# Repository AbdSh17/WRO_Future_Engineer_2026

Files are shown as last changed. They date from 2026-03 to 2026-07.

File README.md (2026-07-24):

<p align="center">
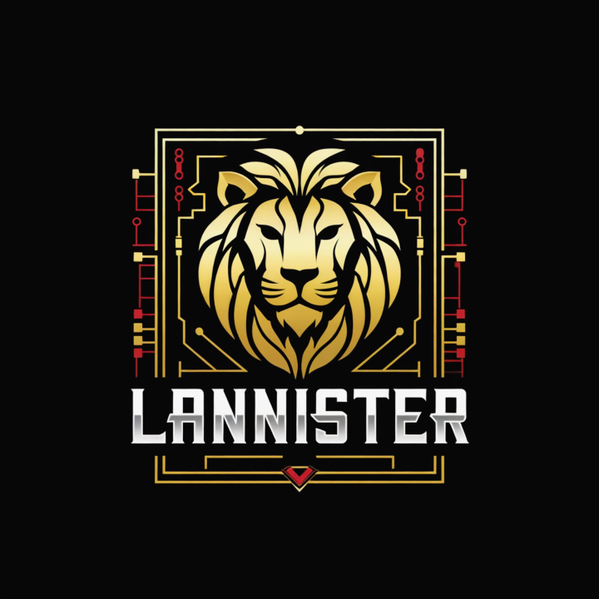
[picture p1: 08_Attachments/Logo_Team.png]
Team Lannister Logo
  
</p>

<h1 align="center">Team Lannister — WRO 2026 Future Engineers</h1>

<p align="center">
  <em>A self-driving car, built from scratch.</em>
</p>

<p align="center">
  <em>Hear me Roar.</em>
</p>

---

## Table of Contents

- [1. The Team](#1-the-team)
- [2. The Challenge](#2-the-challenge)
- [3. Mechanical Design](#3-mechanical-design)
  - [3.1 Chassis — Three Levels](#31-chassis--three-levels)
  - [3.2 Chassis & Deck Drawings](#32-chassis--deck-drawings)
  - [3.3 Steering — Ackermann Geometry](#33-steering--ackermann-geometry)
  - [3.4 Drivetrain](#34-drivetrain)
  - [3.5 Design Iterations](#35-design-iterations)
- [4. Hardware Overview](#4-hardware-overview)
  - [4.1 The Two Brains: ESP32 + Raspberry Pi 5](#41-the-two-brains-esp32--raspberry-pi-5)
  - [4.2 Vision: Raspberry Pi Camera Module 3](#42-vision-raspberry-pi-camera-module-3)
  - [4.3 Bill of Materials](#43-bill-of-materials)
  - [4.4 Power Architecture](#44-power-architecture)
  - [4.5 Wiring](#45-wiring)
- [5. Software](#5-software)
- [6. The Vehicle](#6-the-vehicle)
- [7. Videos](#7-videos)
- [8. Repository Map](#8-repository-map)
- [9. Build & Run](#9-build--run)
- [10. Behind the Build](#10-behind-the-build)

---

## 1. The Team

<table align="center">
<tr>
<td align="center" width="380">
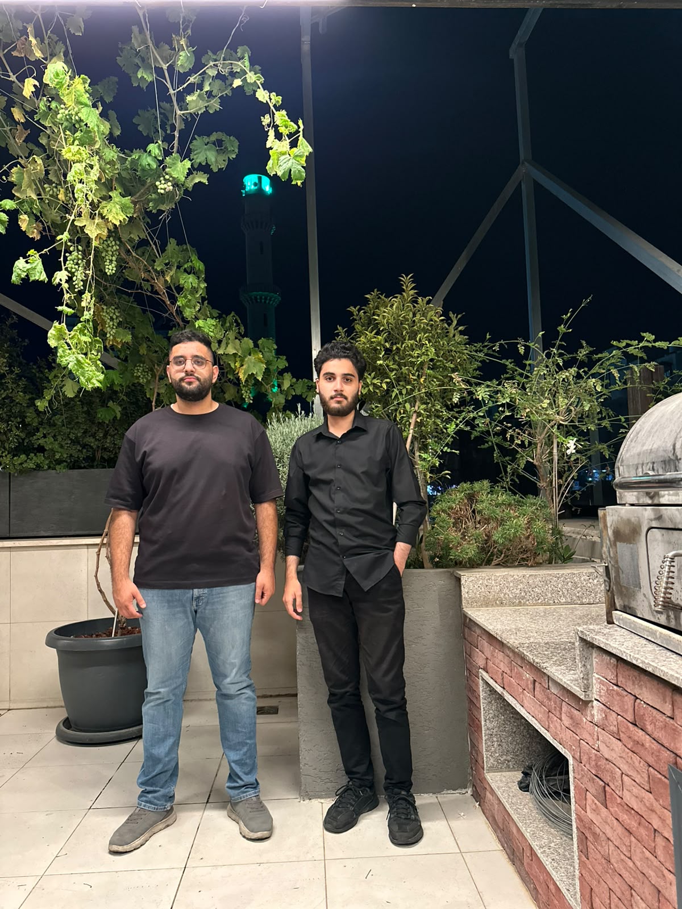
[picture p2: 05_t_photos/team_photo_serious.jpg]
<br/>
<sub><b>The official photo</b></sub>
</td>
<td align="center" width="380">
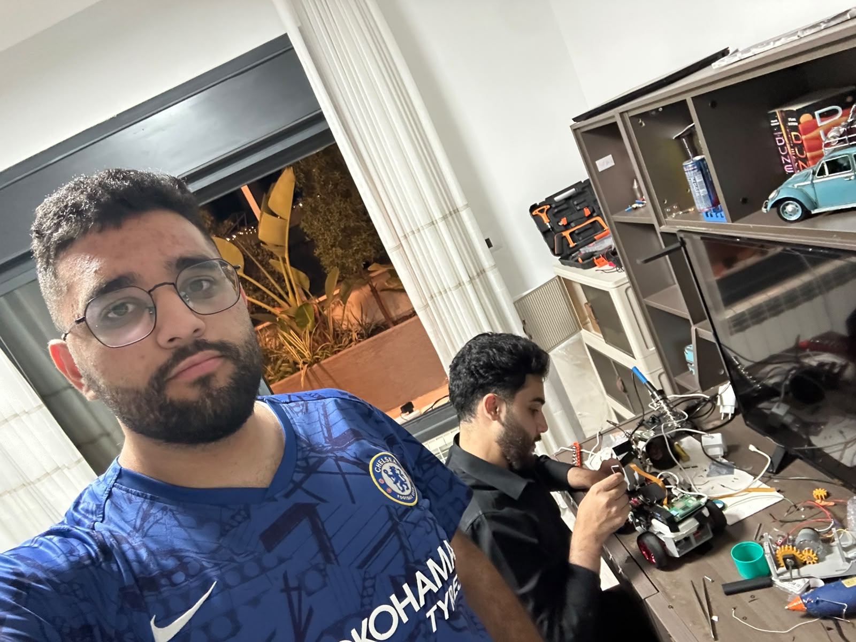
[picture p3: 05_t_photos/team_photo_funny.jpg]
<br/>
<sub><b>The one that actually looks like us</b></sub>
</td>
</tr>
</table>

---

<table align="center">
<tr>
<td align="center" width="300">
<br/>
<sub><b>Abdalraheem Shuaibi</b></sub><br/>
<sub>Hardware & PCB Design / Software</sub>
</td>
</tr>
</table>

I'm a 21-year-old Computer Engineering student at Birzeit University. I started learning embedded systems and firmware development about two years ago — largely self-taught, out of necessity. Structured resources for this kind of work are scarce where I'm from, so my path went from basic circuits and electronics theory all the way to PCB design, and from simple Arduino sketches to FreeRTOS and ESP-IDF, the same stack powering this robot.

Alongside this competition, I've been juggling a graduation project funded by the EU and the Palestinian Ministry of Health — a commitment that's demanded careful time management this season.

This isn't my first attempt at WRO Future Engineers. I competed alone in the 2025 season and things were going well, until a sensor burned out just before the local competition, ending that run early. That experience is a big part of why this repository exists in the form it does now — more testing, more documentation, fewer single points of failure.

---

<table align="center">
<tr>
<td align="center" width="300">
<br/>
<sub><b>Abdulrahman Sawalmeh</b></sub><br/>
<sub>Mechanical Design / Research / Hardware</sub>
</td>
</tr>
</table>

I'm a 21-year-old Computer Engineering student at Birzeit University. My main role on this team is the mechanical side — designing every printed part, building the physical robot, and making sure what looks right on screen actually works when it's sitting on a track. Along the way I also helped with component research, sourcing and buying parts, and sat in on algorithm discussions.

The 3D design side started about three months before this project, entirely self-taught. I picked up Fusion 360 out of curiosity — I thought it looked cool, kept going, and it turned into the thing I spent most of this competition doing. Three months in, a complete custom chassis with 16 printed parts and two rounds of mechanical iteration isn't where I expected to end up when I opened Fusion for the first time.

The hardest part wasn't any single part failing — it was the differential assembly. The obvious fixes for the axial play problem were both blocked by gear clearance on either side, and working around that constraint took longer than the original design. The retaining ring solution is simple in hindsight. It wasn't at the time.

This competition was the first time I built something that had to work in the real world, not just look right on screen. That gap between a model and a physical object that actually does its job — closing it is what made this season worth it.

---

## 2. The Challenge

<p align="center">
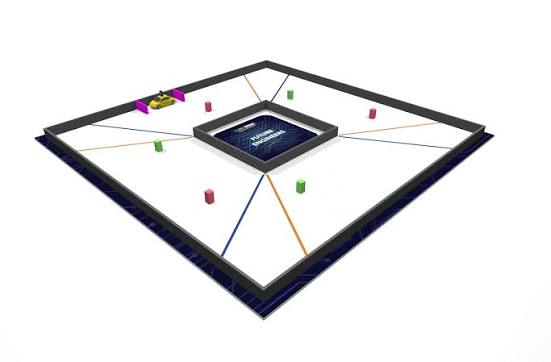
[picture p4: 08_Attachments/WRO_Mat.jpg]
WRO 2026 Future Engineers game field
  
</p>

WRO Future Engineers asks for a vehicle that can drive itself — no remote control, no shortcuts, just sensors, math, and code making decisions in real time. The car has to complete laps around a track that changes every round: walls move, corners narrow, and in the Obstacle Challenge, coloured pillars appear that the car has to read and respond to correctly. Get it wrong, and the round ends early.

It's a small, contained problem on paper. In practice, it touches almost every corner of engineering: mechanical design, power distribution, real-time firmware, computer vision, and the occasional very frustrating GPIO conflict at 2 AM.

---

## 3. Mechanical Design

Every structural part of this vehicle is custom-designed and 3D-printed. Nothing here is off the shelf except the WLTOYS 144001 differential and the wheels — everything else, from the chassis plate to the servo arm, was modelled in Fusion 360 and iterated through at least one physical revision. Full technical documentation, iteration stories, and manufacturing notes live in [`03_Models/00_models.md`](03_Models/00_models.md).

---

### 3.1 Chassis — Three Levels

The 300 × 200 mm footprint limit means the layout grows upward, not outward. One plate — `main_base` (254 × 100 mm) — carries everything, with standoff columns supporting two raised decks above it.

<table align="center">
<tr>
<td align="center" width="500">
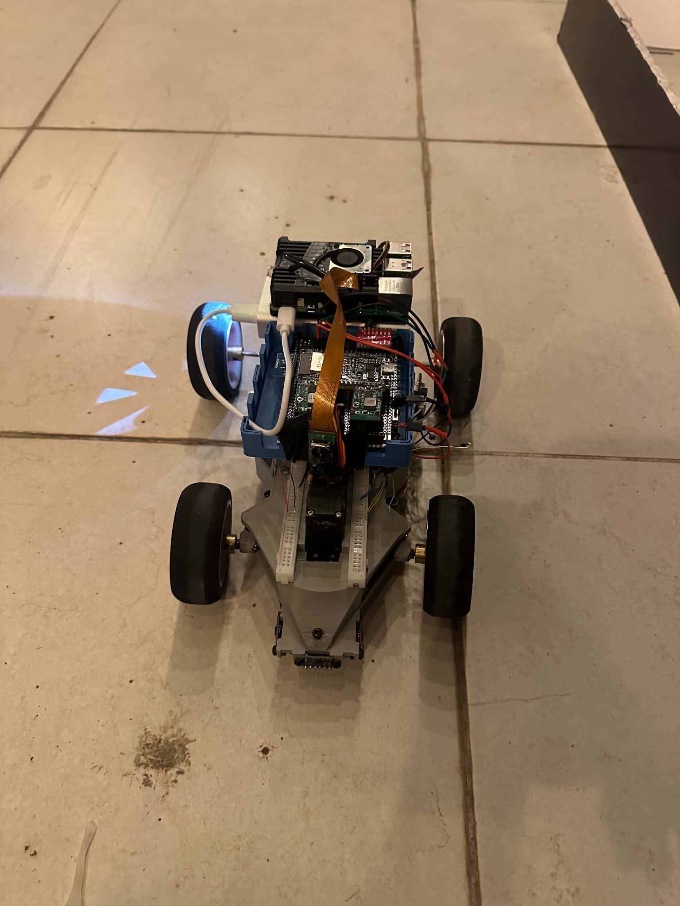
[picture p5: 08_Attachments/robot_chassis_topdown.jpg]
<br/>
<sub><b>Pi 5 and ESP32 stacked on the upper decks, fully wired</b></sub>
</td>
</tr>
</table>

| Level | Part | What lives there |
|---|---|---|
| Ground plate | `main_base` | Motor (mount built into the plate), differential assembly, steering knuckles, column standoffs |
| Front deck | `front_top` | MG996R steering servo, camera mast |
| Middle deck | `middle_top` | Main soldered PCB — see [`04_PCB`](04_PCB/00_PCB.md) |
| Rear deck | `back_top` | Raspberry Pi 5 + power bank |
| Mast | `camera_holder` | Camera Module 3, raised 154.7 mm above the chassis and angled at the track |

Two decisions behind this layout that are worth naming:

**The motor mount is part of the chassis plate, not a bracket.** The JGB37-520 sits in a pocket extruded directly into `main_base`. One fewer part to print, no joint to come loose from vibration, and the motor-to-differential alignment is determined by the geometry of a single piece rather than assembly accuracy.

**Electronics decks are removable.** Each deck comes off with a few screws, so electrical work never requires touching the drivetrain and mechanical work never requires unscrewing electronics. During a competition day, that separation is the difference between a five-minute fix and a full teardown.

---

### 3.2 Chassis & Deck Drawings

Click any drawing to open the full dimensioned PDF.

**Chassis, Decks & Camera**

<table align="center">
<tr>
<td align="center" width="370">
<a href="03_Models/drawings/main_base.pdf">
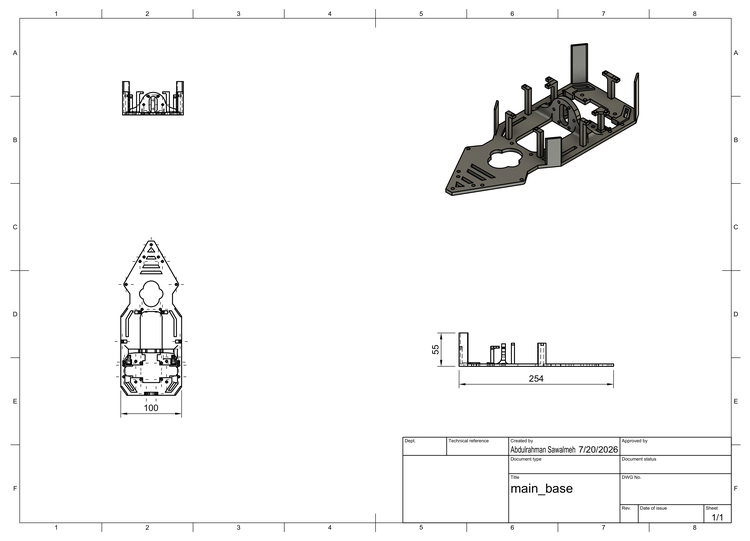
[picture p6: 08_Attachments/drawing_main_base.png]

</a><br/>
<sub><b><a href="03_Models/drawings/main_base.pdf">main_base.pdf</a> — Chassis plate (254 × 100 × 55 mm)</b></sub>
</td>
<td align="center" width="370">
<a href="03_Models/drawings/front_top.pdf">
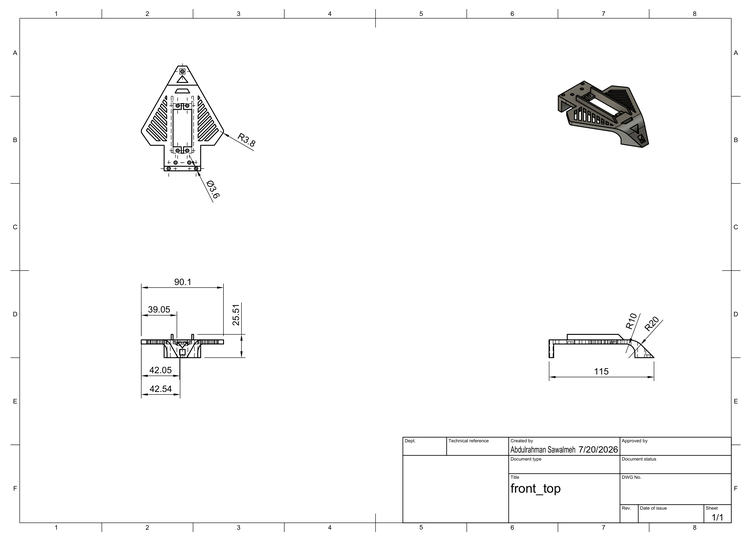
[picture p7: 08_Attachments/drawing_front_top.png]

</a><br/>
<sub><b><a href="03_Models/drawings/front_top.pdf">front_top.pdf</a> — Servo & camera deck (90 × 115 × 25 mm)</b></sub>
</td>
</tr>
<tr>
<td align="center" width="370">
<a href="03_Models/drawings/mid_top.pdf">
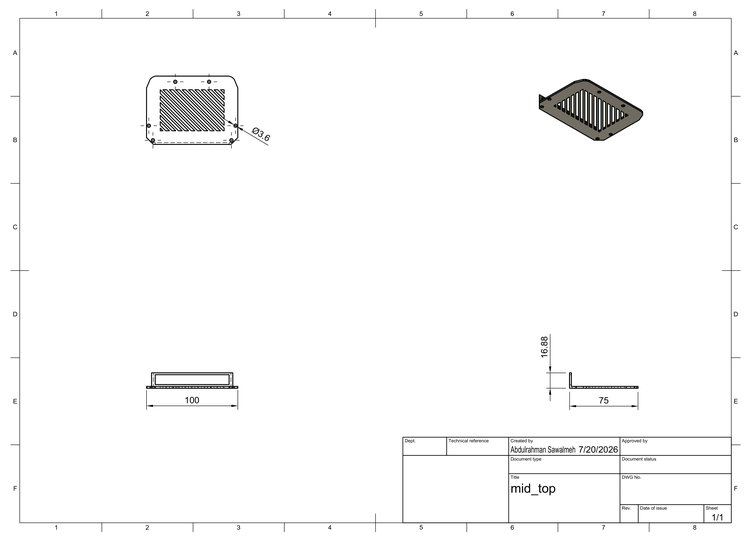
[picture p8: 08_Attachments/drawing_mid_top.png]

</a><br/>
<sub><b><a href="03_Models/drawings/mid_top.pdf">mid_top.pdf</a> — PCB platform (100 × 75 × 17 mm)</b></sub>
</td>
<td align="center" width="370">
<a href="03_Models/drawings/back_top.pdf">
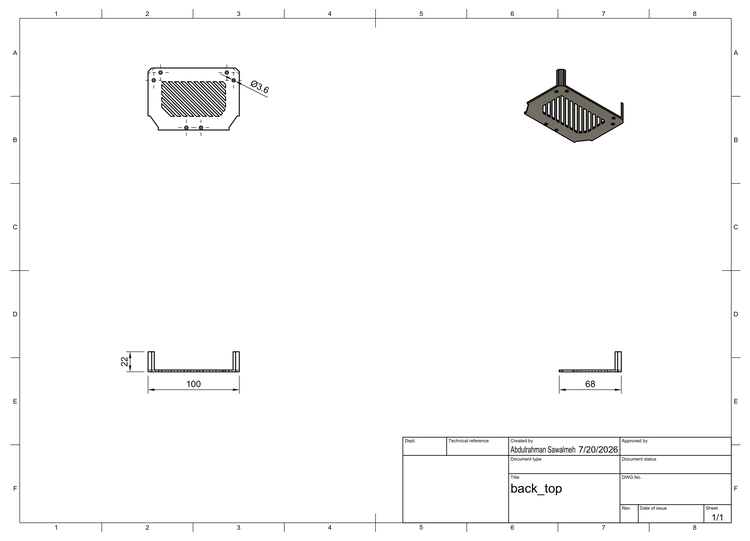
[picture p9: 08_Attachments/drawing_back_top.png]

</a><br/>
<sub><b><a href="03_Models/drawings/back_top.pdf">back_top.pdf</a> — Pi & power bank deck (100 × 68 × 22 mm)</b></sub>
</td>
</tr>
</table>

<table align="center">
<tr>
<td align="center" width="500">
<a href="03_Models/drawings/camera_holder.pdf">
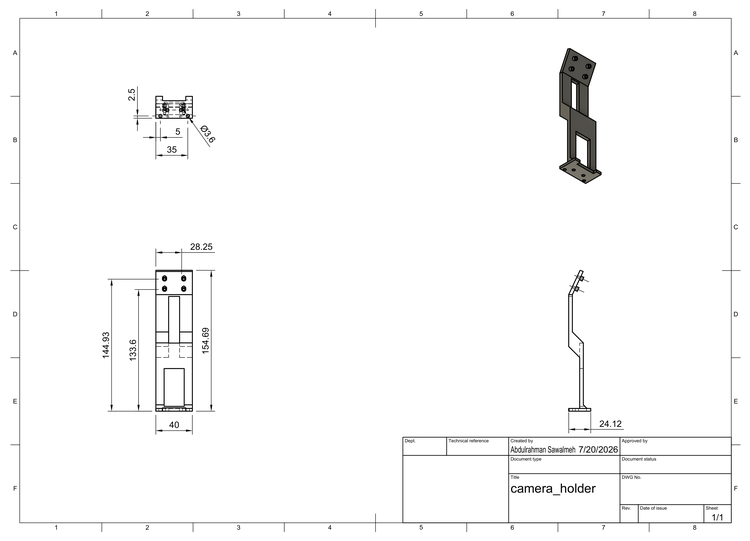
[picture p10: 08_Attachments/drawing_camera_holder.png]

</a><br/>
<sub><b><a href="03_Models/drawings/camera_holder.pdf">camera_holder.pdf</a> — Camera mast (40 × 24 × 154.7 mm) — the tallest printed part, raising the lens above the vehicle body</b></sub>
</td>
</tr>
</table>

---

### 3.3 Steering — Ackermann Geometry

The front wheels don't turn at the same angle — they can't. In any turn, the inner wheel follows a tighter arc than the outer one, so turning both wheels by the same amount always forces one of them to scrub sideways. Ackermann geometry fixes this by angling the steering linkage so the inner wheel always steers sharper than the outer one, pointing every wheel at a common turn center.

<table align="center">
<tr>
<td align="center" width="400">
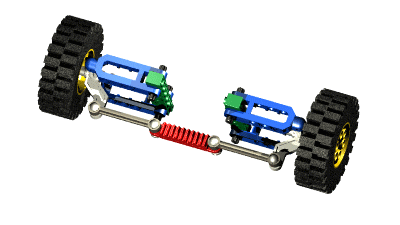
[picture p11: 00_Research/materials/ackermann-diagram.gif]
<br/>
<sub><b>Ackermann geometry in action</b></sub>
</td>
<td align="center" width="400">
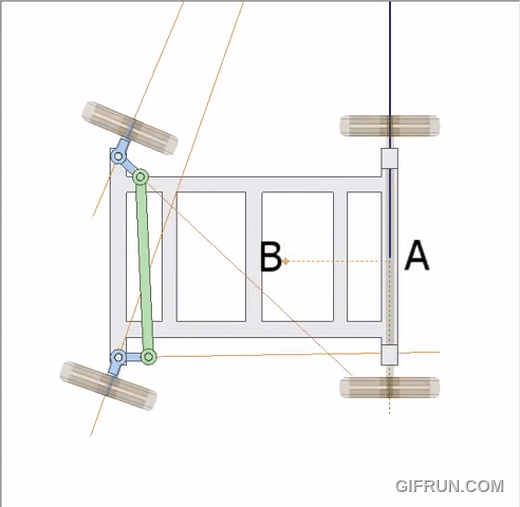
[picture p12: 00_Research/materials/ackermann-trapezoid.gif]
<br/>
<sub><b>The trapezoid linkage</b></sub>
</td>
</tr>
</table>

The geometry is implemented in three printed parts: the `left_knuckle` and `right_knuckle` pivot on kingpins at the chassis, and the `ackerman_rod` connects both knuckle eyes with a servo arm driving its center. The tie-rod eyes are angled inward so the line through each kingpin and its eye converges at the rear axle — the Ackermann condition. Verified directly in CAD:

<table align="center">
<tr>
<td align="center" width="350">
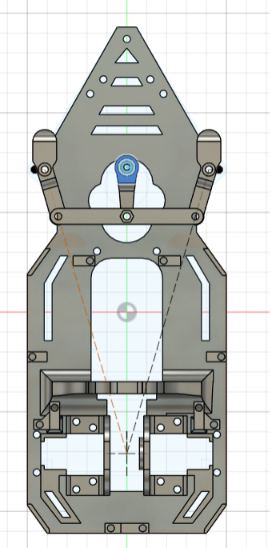
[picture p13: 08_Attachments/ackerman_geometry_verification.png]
<br/>
<sub><b>Top view in Fusion 360 — construction lines from the steering pivots converge at the rear axle centerline</b></sub>
</td>
</tr>
</table>

Full geometry, math, and the comparison against parallel steering is in [`00_Research/04_mechanical/02_ackermann-steering.md`](00_Research/04_mechanical/02_ackermann-steering.md). The torque requirement that selected the MG996R servo is in [`00_Research/03_components_selection/02_servo-torque-requirement.md`](00_Research/03_components_selection/02_servo-torque-requirement.md).

**Steering parts drawings**

<table align="center">
<tr>
<td align="center" width="250">
<a href="03_Models/drawings/ackerman_rod.pdf">
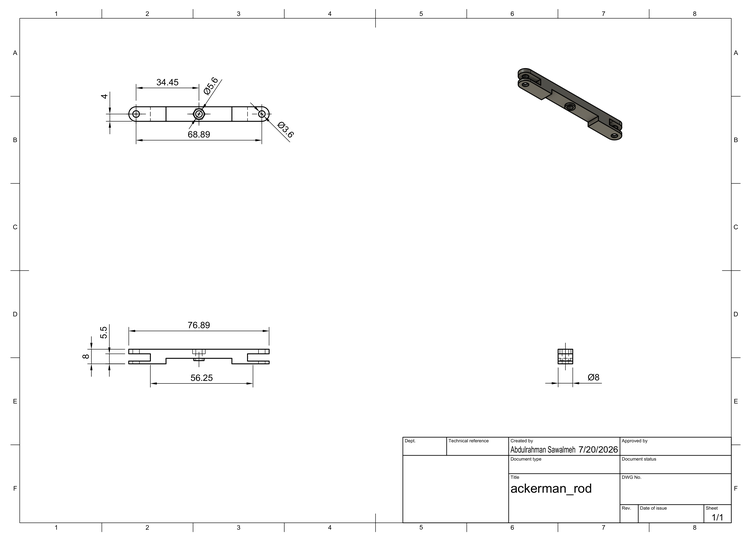
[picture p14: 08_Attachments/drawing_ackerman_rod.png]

</a><br/>
<sub><b><a href="03_Models/drawings/ackerman_rod.pdf">ackerman_rod.pdf</a><br/>Tie rod (76.9 × 8 × 8 mm)</b></sub>
</td>
<td align="center" width="250">
<a href="03_Models/drawings/knuckles.pdf">
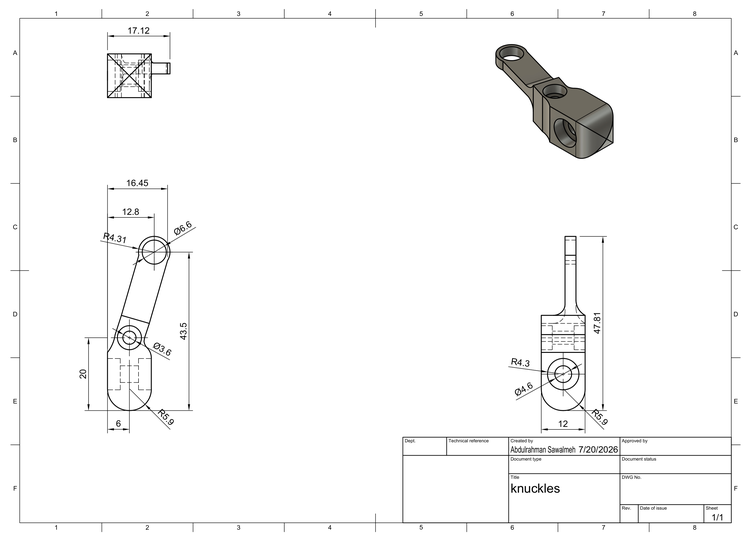
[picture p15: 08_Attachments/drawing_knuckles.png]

</a><br/>
<sub><b><a href="03_Models/drawings/knuckles.pdf">knuckles.pdf</a><br/>L/R knuckles (17 × 47.8 × 12 mm)</b></sub>
</td>
<td align="center" width="250">
<a href="03_Models/drawings/servo_arm.pdf">
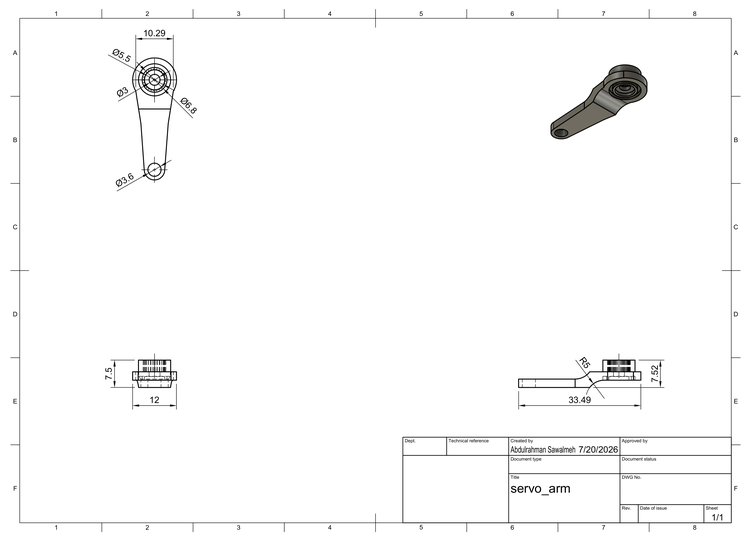
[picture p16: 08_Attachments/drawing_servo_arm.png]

</a><br/>
<sub><b><a href="03_Models/drawings/servo_arm.pdf">servo_arm.pdf</a><br/>Servo arm (33.5 × 12 × 7.5 mm)</b></sub>
</td>
</tr>
</table>

---

### 3.4 Drivetrain

A single JGB37-520 motor drives both rear wheels through a WLTOYS 144001 open differential — an off-the-shelf RC part that needed a fully custom mounting system because it was never designed for this chassis. The mounting system is five printed parts around a single off-the-shelf differential.

<table align="center">
<tr>
<td align="center" width="400">
<br/>
<sub><b>The differential in motion</b></sub>
</td>
<td align="center" width="400">
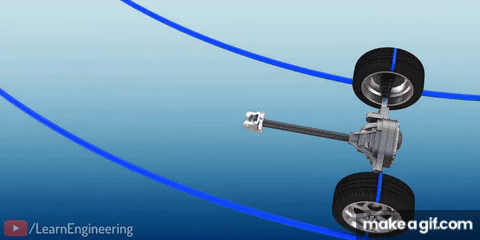
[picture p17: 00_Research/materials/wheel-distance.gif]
<br/>
<sub><b>Inner vs. outer wheel arc — why it matters</b></sub>
</td>
</tr>
</table>

Torque path: motor → bevel pinion (`motor_gear`) → differential crown → drive cups (`differantial_cup`) → 4 mm shafts → rear wheels. The differential splits torque purely mechanically — one motor, gears doing the work — which keeps us compliant with rule 11.5 (electronic differentials, one motor per side, are banned) while still letting the two rear wheels rotate at different speeds in corners.

Full drivetrain reasoning is in [`00_Research/04_mechanical/01_Differential.md`](00_Research/04_mechanical/01_Differential.md).

**Drivetrain parts drawings**

<table align="center">
<tr>
<td align="center" width="370">
<a href="03_Models/drawings/motor_gear.pdf">
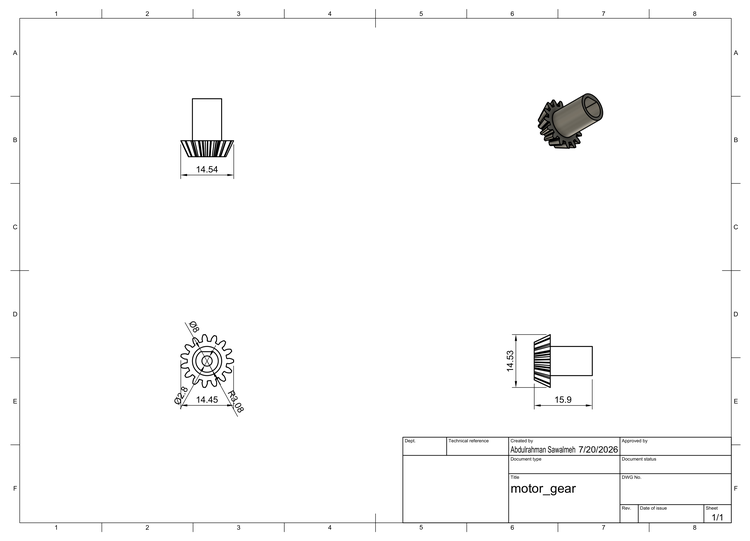
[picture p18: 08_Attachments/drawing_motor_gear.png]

</a><br/>
<sub><b><a href="03_Models/drawings/motor_gear.pdf">motor_gear.pdf</a> — Bevel pinion (14.5 × 15.9 × 14.5 mm)</b></sub>
</td>
<td align="center" width="370">
<a href="03_Models/drawings/differantial_rings_holder.pdf">
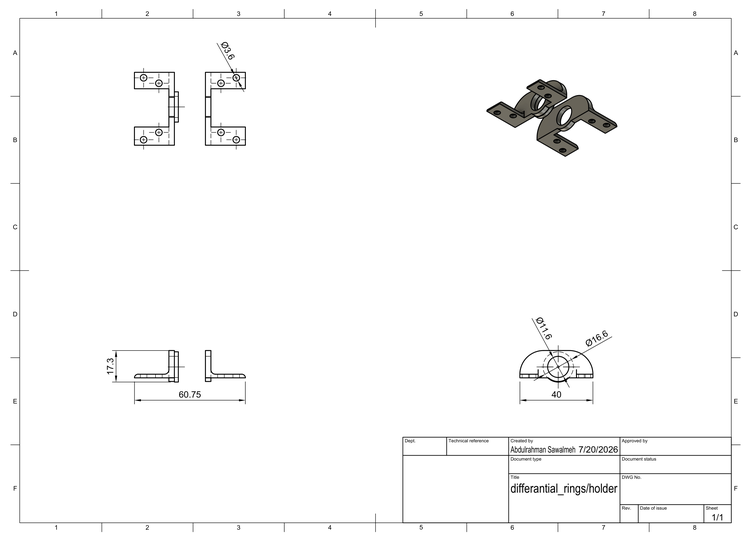
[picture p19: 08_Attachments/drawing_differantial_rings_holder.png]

</a><br/>
<sub><b><a href="03_Models/drawings/differantial_rings&holder.pdf">differantial_rings&holder.pdf</a> — Carrier rings + retaining ring</b></sub>
</td>
</tr>
<tr>
<td align="center" width="370">
<a href="03_Models/drawings/differantial_cup.pdf">
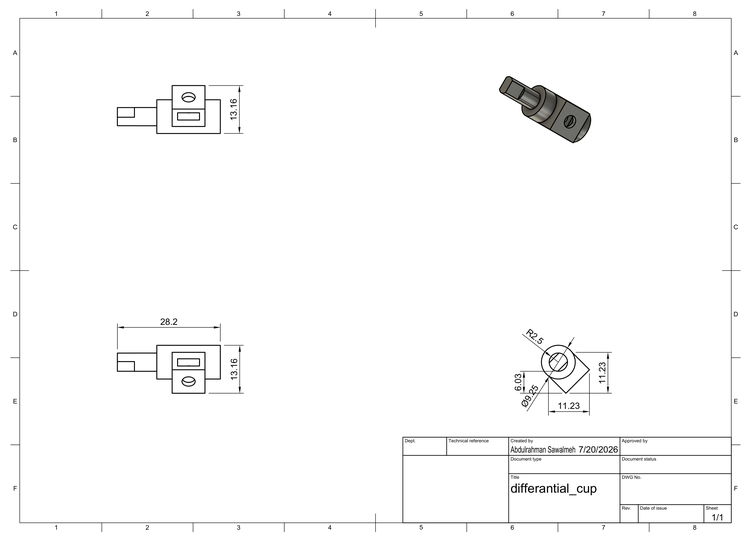
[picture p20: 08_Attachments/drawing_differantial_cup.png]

</a><br/>
<sub><b><a href="03_Models/drawings/differantial_cup.pdf">differantial_cup.pdf</a> — Drive coupling cup (28.2 × 13.2 × 13.2 mm)</b></sub>
</td>
<td align="center" width="370">
<a href="03_Models/drawings/shaft_holder.pdf">
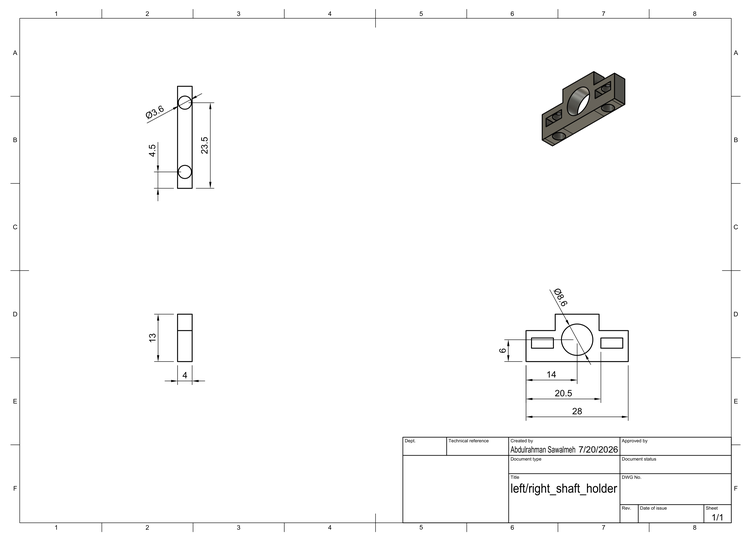
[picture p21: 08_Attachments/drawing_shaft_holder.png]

</a><br/>
<sub><b><a href="03_Models/drawings/shaft_holder.pdf">shaft_holder.pdf</a> — Outboard bearing block (28 × 13 mm, 4 mm shaft)</b></sub>
</td>
</tr>
</table>

---

### 3.5 Design Iterations

The drivetrain didn't work on the first try. Two physical problems had to be solved before the car drove properly — both visible in the current set of parts.

**Iteration 1 — Differential axial play.** The differential could slide sideways between its two carrier rings, shifting the bevel gear mesh and causing skips under load. The obvious fixes — thicken one carrier ring inward — were blocked by the motor's pinion on one side and a gear on the other. The solution was a separate 2.25 mm retaining ring (`differantial_holder`) glued to the right carrier, surrounding the differential bearing and closing the gap without entering either gear's space. A packaging constraint blocking both obvious solutions, forcing a third one.

**Iteration 2 — Rear wheel tilt.** Each drive shaft was originally supported only at its inboard end, at the differential carrier ring. The wheel hung on the free end of a cantilever and visibly tilted. Adding outboard bearing blocks (`left_shaft_holder`, `right_shaft_holder`) converted every shaft from a cantilevered load to a two-point supported one. The tilt disappeared.

Full iteration writeup with technical detail: [`03_Models/00_models.md#design-iterations`](03_Models/00_models.md#5-design-iterations)

---

## 4. Hardware Overview

### 4.1 The Two Brains: ESP32 + Raspberry Pi 5

The robot runs on two separate computers, each doing a different job.

<table align="center">
<tr>
<td align="center" width="260">
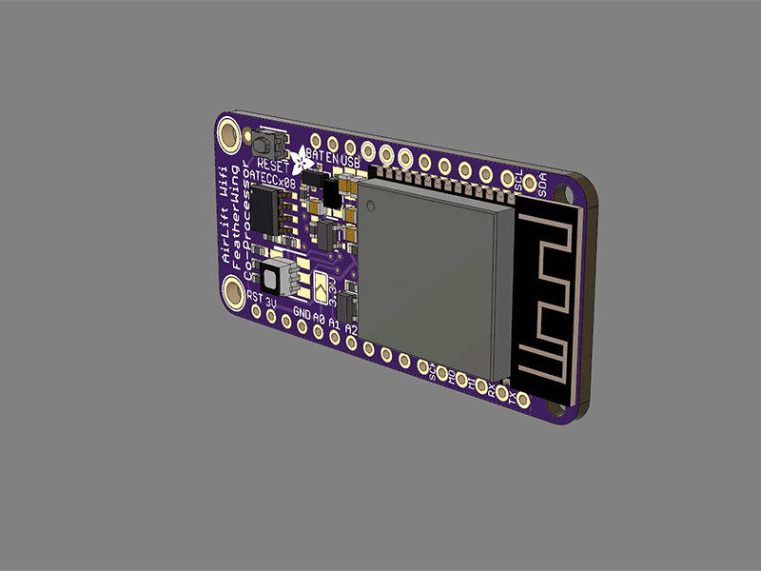
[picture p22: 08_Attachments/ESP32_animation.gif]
<br/>
<sub><b>ESP32 — real-time control</b></sub>
</td>
<td align="center" width="260">
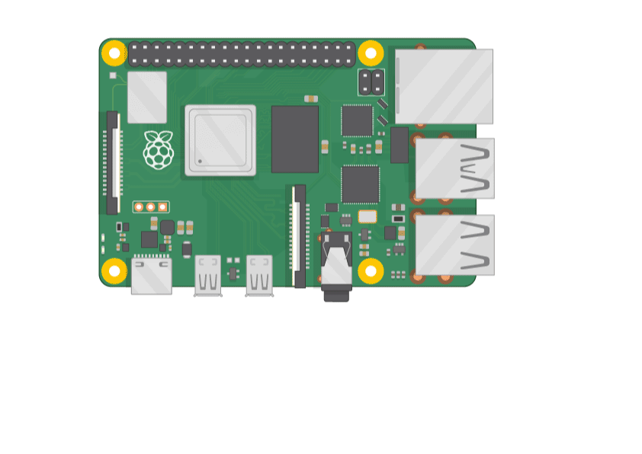
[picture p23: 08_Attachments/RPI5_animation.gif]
<br/>
<sub><b>Raspberry Pi 5 — vision</b></sub>
</td>
</tr>
</table>

The **ESP32** handles everything that has to happen in real time and can't afford to be late: reading the ToF sensors, reading the IMU, driving the motor, driving the steering servo, and running the state machine that decides what the car does next. It runs FreeRTOS, with each task — sensing, control, algorithm — kept strictly separated so a slow camera frame on the other board can never introduce jitter into a steering correction.

The **Raspberry Pi 5** is reserved for vision. Camera processing is comparatively heavy and doesn't need to run at the same tight, predictable cadence as motor control — so it lives on its own board entirely, talking to the ESP32 over UART.

<p align="center">
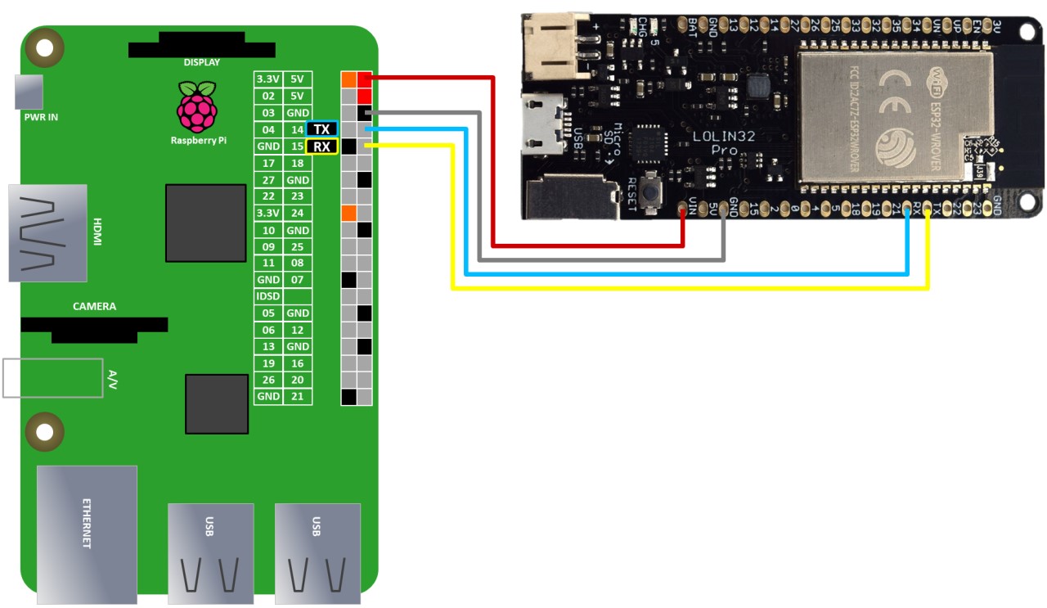
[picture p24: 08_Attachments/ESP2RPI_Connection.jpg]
ESP32 to Raspberry Pi connection
  
</p>
<p align="center"><sub><b>How the two boards talk to each other</b></sub></p>

Splitting the compute this way means a heavy vision frame never stalls a steering correction, and a firmware crash on the ESP32 doesn't take the camera pipeline down with it.

---

### 4.2 Vision: Raspberry Pi Camera Module 3

<table align="center">
<tr>
<td align="center" width="220">
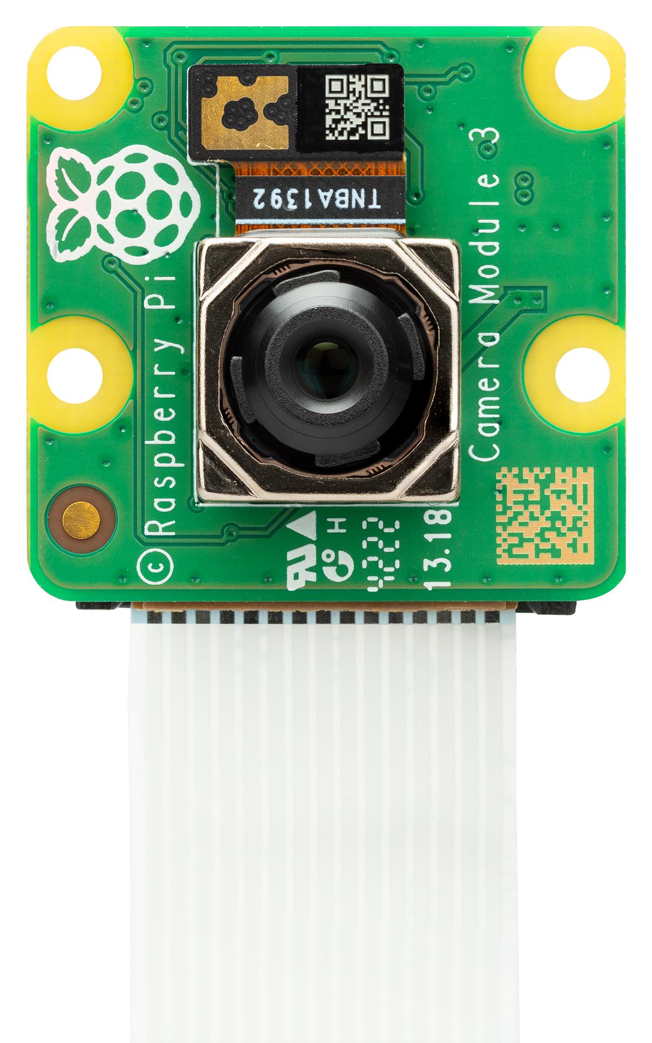
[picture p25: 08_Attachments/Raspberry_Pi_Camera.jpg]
<br/>
<sub><b>Camera Module 3, wide-angle</b></sub>
</td>
</tr>
</table>

We're using the **Raspberry Pi Camera Module 3**, wide-angle variant (~120° diagonal FoV), connected over the Pi 5's CSI port. The wide field of view matters here — the car needs to see pillars and track edges well before it's close enough for a narrow lens to catch them, giving the vision pipeline more time to make a decision.

<table align="center">
<tr>
<td align="center" width="400">
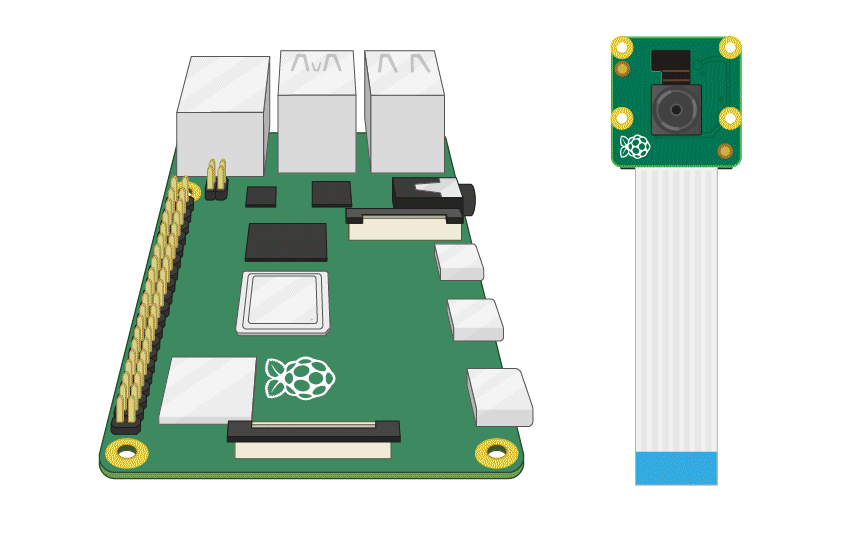
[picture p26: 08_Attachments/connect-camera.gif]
<br/>
<sub><b>Connecting the camera</b></sub>
</td>
</tr>
</table>

---

### 4.3 Bill of Materials

Every component on this robot was chosen against a calculated requirement first, not picked off a shelf. The motor's stall torque, the servo's stall torque, even the capacitor and resistor values, all trace back to a number derived in [`00_Research`](00_Research) before a single part was ordered.

---

**Compute — the two things that think**

<table align="center">
<tr>
<td align="center" width="240">
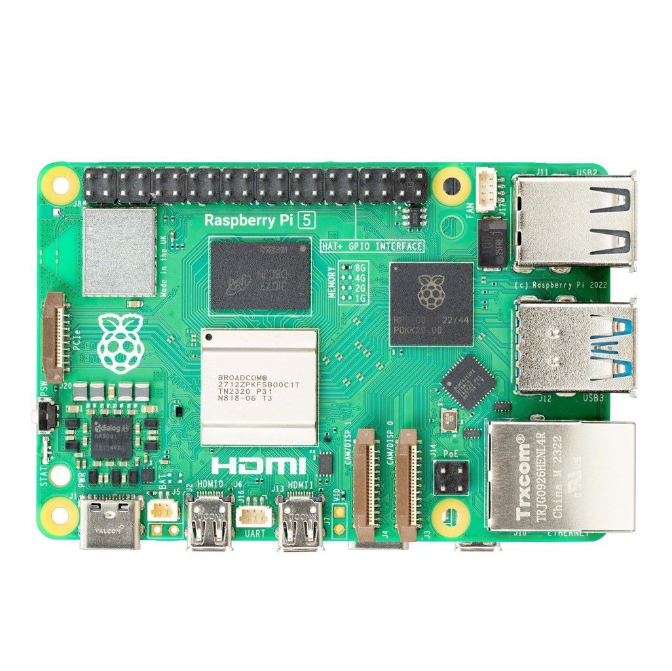
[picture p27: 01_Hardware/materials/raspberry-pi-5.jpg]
<br/>
<sub><b>Raspberry Pi 5</b></sub>
</td>
<td align="center" width="240">
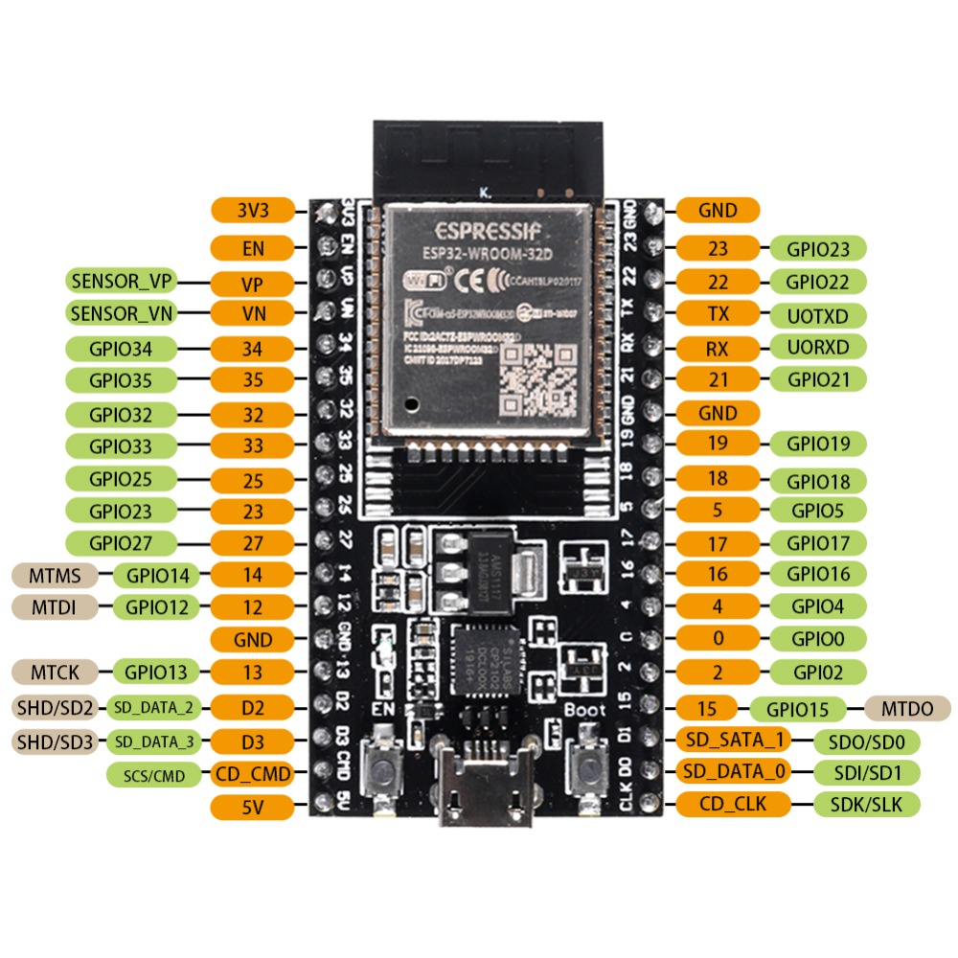
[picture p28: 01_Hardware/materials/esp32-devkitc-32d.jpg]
<br/>
<sub><b>ESP32-DEVKITC-32D</b></sub>
</td>
</tr>
</table>

The **Raspberry Pi 5** handles vision — capturing and processing camera frames, deciding where pillars are. The **ESP32-DEVKITC-32D** handles everything that needs to happen on a strict, predictable schedule: reading sensors, driving the motor, driving the servo, and running the state machine.

---

**Sensors — the three things that feel the track**

<table align="center">
<tr>
<td align="center" width="240">
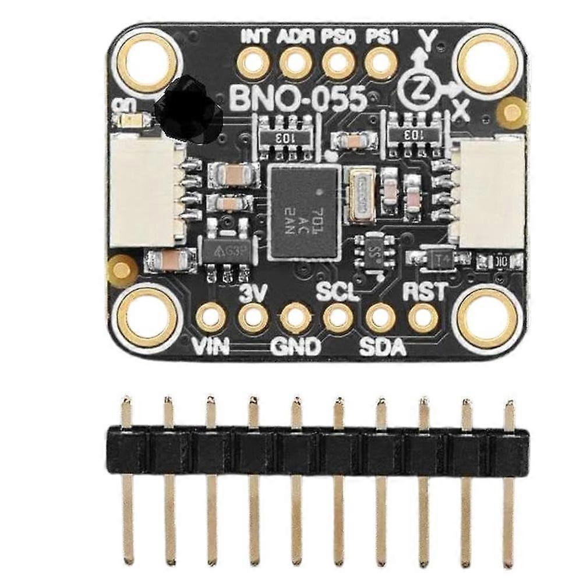
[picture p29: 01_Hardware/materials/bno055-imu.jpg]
<br/>
<sub><b>BNO055 IMU</b></sub>
</td>
<td align="center" width="240">
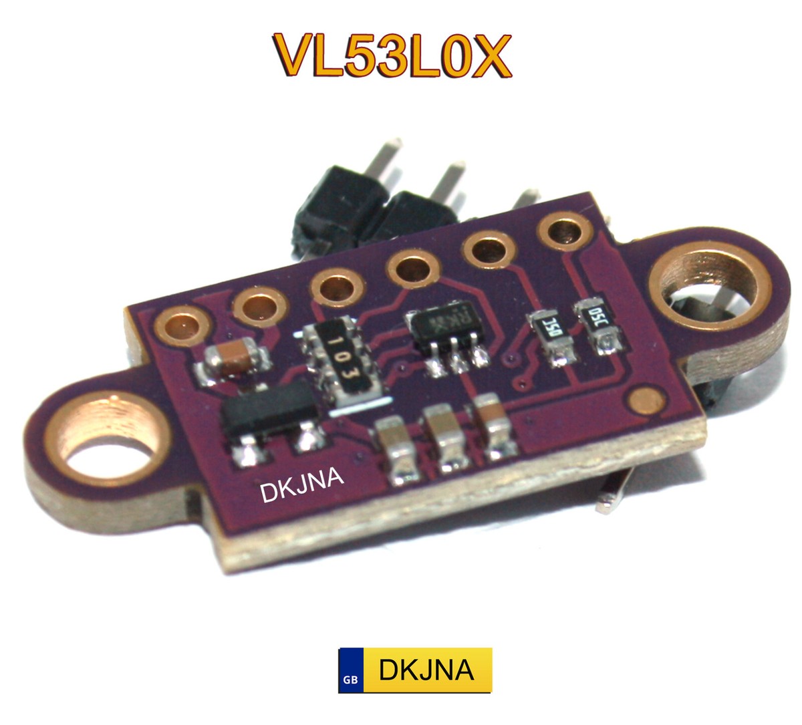
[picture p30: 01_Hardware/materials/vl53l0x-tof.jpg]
<br/>
<sub><b>VL53L0X ToF ×3</b></sub>
</td>
</tr>
</table>

The **BNO055 IMU** gives the robot an absolute sense of heading — it's what lets the car hold a straight line and execute a clean 90° turn without drifting. Three **VL53L0X ToF sensors** (front, left, right) act as the robot's proximity sense. A **hall-effect encoder** on the drive shaft provides distance and speed feedback for odometry.

---

**Actuators — the two things that move the car**

<table align="center">
<tr>
<td align="center" width="240">
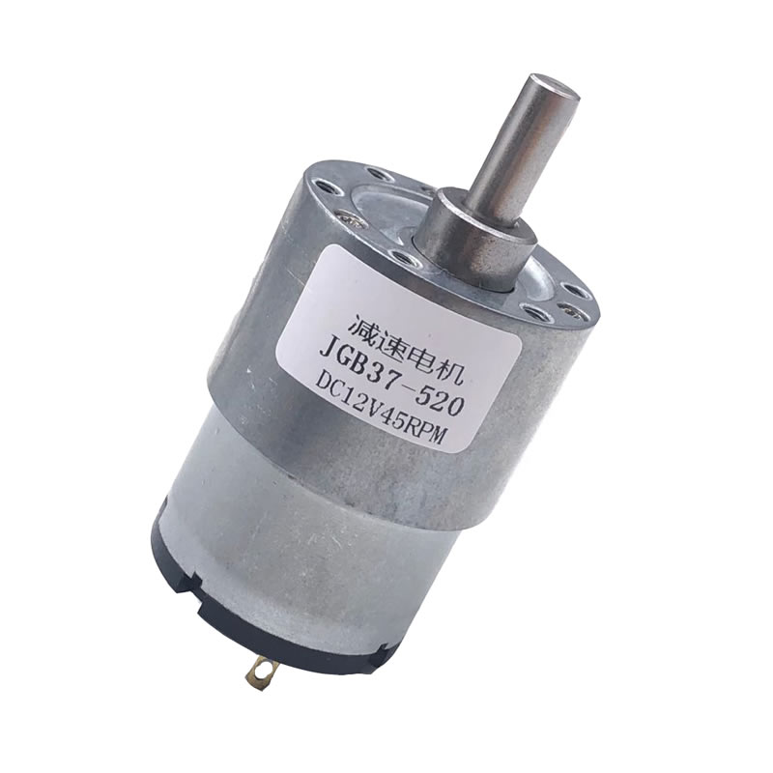
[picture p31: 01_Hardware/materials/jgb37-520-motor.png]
<br/>
<sub><b>JGB37-520 DC motor</b></sub>
</td>
<td align="center" width="240">
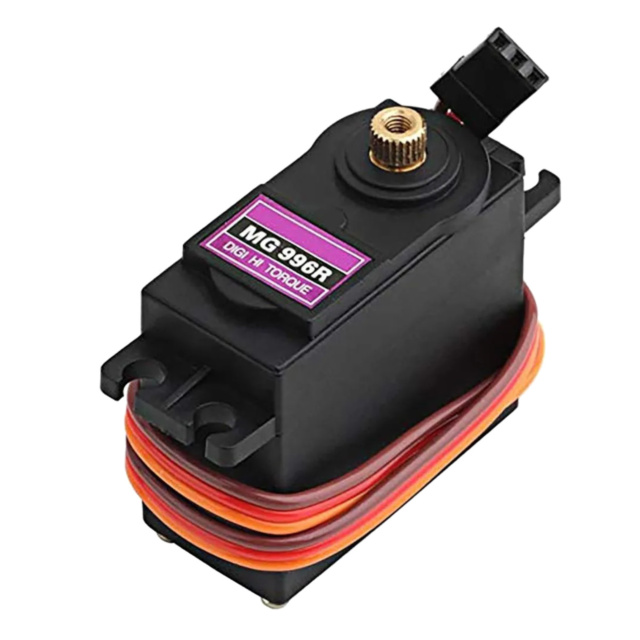
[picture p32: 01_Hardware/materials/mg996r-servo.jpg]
<br/>
<sub><b>MG996R servo</b></sub>
</td>
</tr>
</table>

The **JGB37-520 DC gear motor** drives the rear axle through the differential — sized so its stall torque clears ≥ 0.6 kg·cm, with full derivation in [`01_motor-selection-criteria.md`](00_Research/03_components_selection/01_motor-selection-criteria.md). The **MG996R servo** handles Ackermann steering up front, sized to clear ≥ 9.3 kg·cm against tire scrub — worked out in [`02_servo-torque-requirement.md`](00_Research/03_components_selection/02_servo-torque-requirement.md).

---

**Power — what keeps it all alive**

<table align="center">
<tr>
<td align="center" width="240">
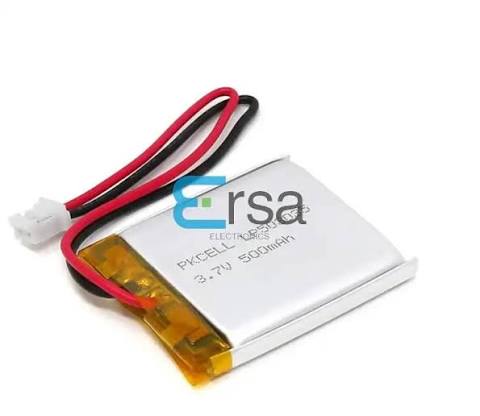
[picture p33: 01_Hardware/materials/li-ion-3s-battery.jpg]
<br/>
<sub><b>3S Li-Ion battery</b></sub>
</td>
<td align="center" width="240">
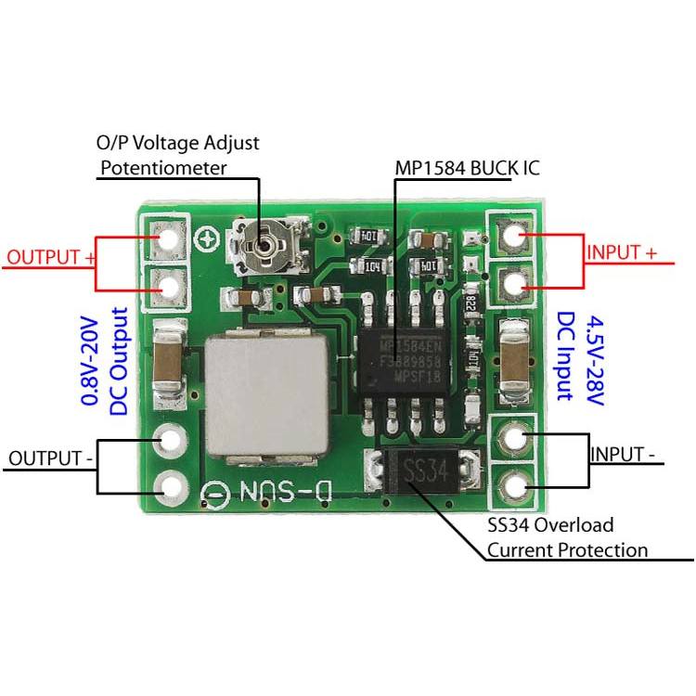
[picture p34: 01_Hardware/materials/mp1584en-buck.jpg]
<br/>
<sub><b>MP1584EN buck converter</b></sub>
</td>
<td align="center" width="240">
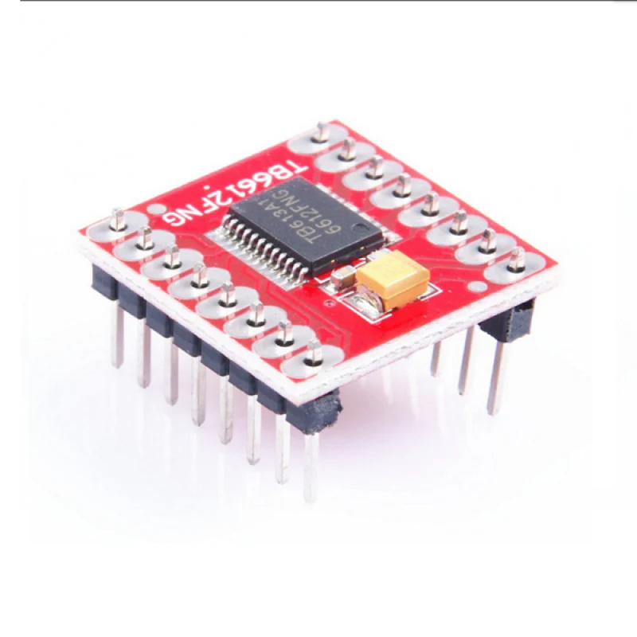
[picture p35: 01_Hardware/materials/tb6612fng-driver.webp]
<br/>
<sub><b>TB6612FNG driver</b></sub>
</td>
</tr>
</table>

A single **3S Li-Ion battery** feeds everything. Two **MP1584EN buck converters** split that into an isolated 5V logic rail and a 6V servo rail. The **TB6612FNG** H-bridge lets the ESP32's low-current logic pins control the drive motor's much higher current draw.

Full parts list, quantities, and links back to every underlying calculation: [`01_Hardware/01_bill-of-materials.md`](01_Hardware/01_bill-of-materials.md).

---

### 4.4 Power Architecture

<p align="center">
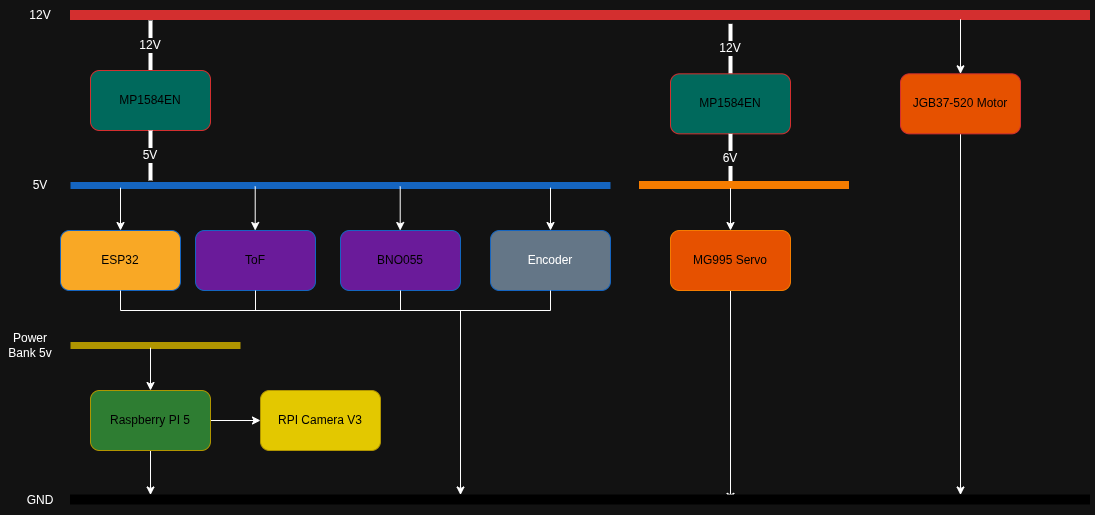
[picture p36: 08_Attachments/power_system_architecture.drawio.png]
Power system architecture
  
</p>
<p align="center"><sub><b>The full power rail layout, battery to load</b></sub></p>

The robot runs on a single 3S Li-Ion battery feeding two independent MP1584EN buck converters — one 5V rail for logic (ESP32, sensors), one 6V rail dedicated entirely to the steering servo. The drive motor draws directly from the battery through the TB6612FNG, bypassing both regulators entirely.

**Why isolate the servo?** Its stall current spikes to roughly 2.5A when it hits mechanical resistance — over eight times the entire logic rail's typical draw. If that spike shared a rail with the ESP32, it could sag the voltage enough to brown-out reset the microcontroller mid-turn. Isolating the rail means a stall event only affects the servo — the ESP32 keeps running, uninterrupted.

**Why capacitors matter here:** every regulator and every IC on these rails leans on a decoupling or bulk capacitor to survive sudden current demand. A capacitor behaves like a small local reservoir of charge — it can dump current instantly in a way a battery several centimeters away, through resistive wire, simply cannot react to fast enough.

<table align="center">
<tr>
<td align="center" width="440">
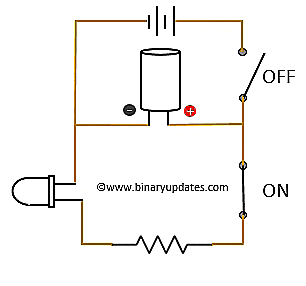
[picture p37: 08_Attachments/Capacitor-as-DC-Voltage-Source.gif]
<br/>
<sub><b>A capacitor acting as a local DC source</b></sub>
</td>
</tr>
</table>

Full current budget, capacitor sizing, and the math: [`01_Hardware/02_power-architecture.md`](01_Hardware/02_power-architecture.md) and [`00_Research/03_components_selection/03_passive-components.md`](00_Research/03_components_selection/03_passive-components.md).

---

### 4.5 Wiring

<p align="center">
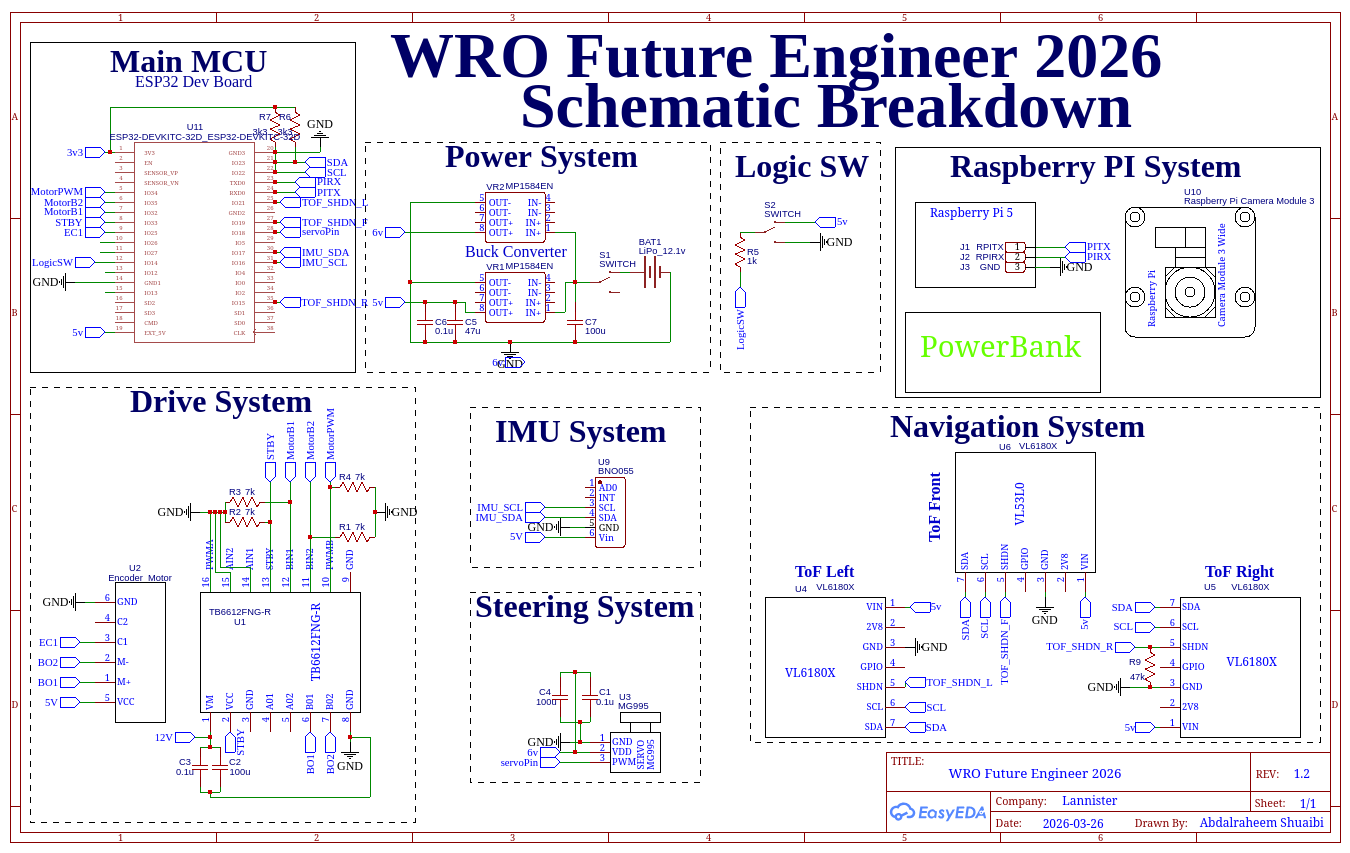
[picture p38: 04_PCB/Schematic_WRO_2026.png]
Full circuit schematic
  
</p>
<p align="center"><sub><b>The full circuit, as wired on the robot today</b></sub></p>

Two separate I2C buses keep the ToF sensors (which need XSHUT address remapping) electrically apart from the IMU, so a slow or stuck sensor on one bus can never stall the other. Every pin assignment is pulled directly from source code — full pin-by-pin detail: [`01_Hardware/03_wiring.md`](01_Hardware/03_wiring.md).

---

## 5. Software

The robot's software is split the same way the hardware is: the **ESP32** makes every decision that has to happen on a strict clock, and the **Raspberry Pi 5** handles everything that's too heavy to run at that pace — mainly camera vision. The two talk to each other over a single UART link, and neither one waits around for the other.

---

### 5.1 Architecture Overview

Three layers, each with one job, and none of them reaching into the others:

- **Sensing layer** — dedicated tasks that only read hardware and publish the result. They never make decisions.
- **Control layer** — `control_task`, the highest-priority task on the board. Executes PID controllers and writes to the motor and servo. Never decides *where* to go, only *how* to get there.
- **Decision layer** — `algorithm_task`, the state machine. Reads what sensing published, decides what should happen next, tells control through an explicit API (`ctrl_request_turn()`, `ctrl_request_forward()`). Never touches a GPIO directly.

<table align="center">
<tr>
<td align="center" width="820">
<br/>
<sub><b>Five tasks, one shared-state layer, one direction of data flow</b></sub>
</td>
</tr>
</table>

---

### 5.2 FreeRTOS Task Architecture

| Task | Period | Priority | Job |
|---|---|---|---|
| `control_task` | 50 ms | 6 (highest) | Runs the active PID controller, drives the servo and motor |
| `imu_task` | 10 ms | 5 | Reads the BNO055, publishes yaw |
| `tof_task` | 20 ms | 5 | Reads the front VL53L0X, publishes distance + wall flags |
| `rpi_task` | 20 ms | 5 | Parses UART lines from the Pi, publishes nav + obstacle data |
| `algorithm_task` | 50 ms | 4 | Reads everything above, runs the state machine |

`control_task` outranks `algorithm_task` on purpose — a state machine that runs a few milliseconds late is invisible to the robot; a jittery servo isn't. The encoder uses an ISR with no task at all, so there's no polling loop and one less thing that can stall.

---

### 5.3 Sensor Data Flow

<table align="center">
<tr>
<td align="center" width="670">
<br/>
<sub><b>From raw signal to driving decision, four independent pipelines</b></sub>
</td>
</tr>
</table>

Every published value carries an age. `algorithm_task` never trusts a stale reading — if the Pi link goes quiet for more than 500 ms, the algorithm falls back to holding position rather than steering on data that might not reflect the real world anymore.

---

### 5.4 Algorithm — Open Challenge

<table align="center">
<tr>
<td align="center" width="570">
<br/>
<sub><b>The full Open Challenge state machine, as implemented in <code>task_algorithm.cpp</code></b></sub>
</td>
</tr>
</table>

**State by state:**

1. **`STATE_IDLE`** — resets everything (encoder, turn count, lap count) and starts driving forward, holding heading 0°.
2. **`STATE_DETECT_DIR`** — since starting position and track direction are randomized, the robot drives straight and watches both sides through the Pi camera until one side's wall-presence score drops below the open threshold for three consecutive frames — that's the committed direction for the full run.
3. **`STATE_FORWARD`** — main driving state. Holds heading with IMU-based PID, watches the committed side and the front ToF for the next corner.
4. **`STATE_TURNING`** — once a corner is confirmed, hands off to `turn_control` for a clean 90° turn using IMU feedback, independent of the forward heading-hold controller.
5. Repeat until three laps and twelve turns are done.
6. **`STATE_FINISH`** — final stretch back, sized using the length of the very first straight recorded on lap one.

A front-wall emergency check runs in every driving state — if the ToF reports a wall closer than the emergency threshold, the robot stops immediately and falls back to `STATE_IDLE`.

**Why side ToF sensors aren't in the flowchart:** corner detection was replaced by the Pi camera's wall-presence score (`nav_left` / `nav_right`), which gives a wider, more forward-looking view of the corridor than a single-point distance reading.

---

### 5.5 Algorithm — Obstacle Challenge

*Not implemented yet — `task_algorithm.cpp` currently only contains the Open Challenge state machine above.*

The plan: the Pi already reports pillar color, distance, and lateral offset (`obst_color`, `obst_distance_mm`, `obst_lateral_mm`) over the same UART link. The ESP32 will use that to bias the heading-hold target left or right by the correct margin — pass red on the right, green on the left — timed against the encoder rather than reacting frame-by-frame, so a single noisy detection can't cause a swerve.

*Flowchart and full write-up will be added once the logic is written and tested.*

---

### 5.6 PID Control & Tuning

Both the turn and heading-hold controllers run on the same underlying `pid_update()` function, tuned very differently because they're solving different problems.

<table align="center">
<tr>
<td align="center" width="720">
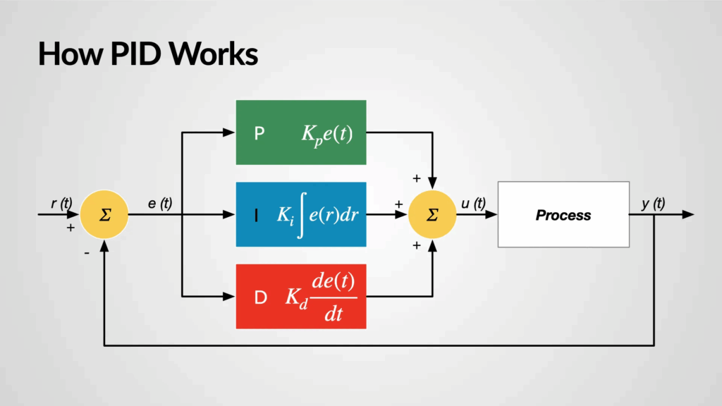
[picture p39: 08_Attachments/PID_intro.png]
<br/>
<sub><b>The closed loop: target heading in, yaw out, error drives the correction</b></sub>
</td>
</tr>
</table>

| | `turn_control` | `forward_control` |
|---|---|---|
| **Job** | Execute a fast, accurate 90° turn | Hold a straight heading, correcting small drift |
| **Kp** | 0.8 | 2.5 |
| **Ki** | 0.075 | 0.15 |
| **Kd** | 0.055 | 0.02 |
| **Output clamp** | ±30° | ±45° |
| **Settle condition** | within ±20° for 6 consecutive cycles | continuous |

The difference in gains comes directly from what each controller corrects: `turn_control` chases a large step change (up to 90°) so a lower Kp is enough to move it without risking a hard overshoot. `forward_control` only ever corrects small drift so it needs a sharper Kp to react to tiny errors quickly, with a tighter output clamp so a heading correction never looks like a turn.

**Tuning process:**

<table align="center">
<tr>
<td align="center" width="1370">
<br/>
<sub><b>The order we followed for both controllers</b></sub>
</td>
</tr>
</table>

Zero D and I → raise P until the response is close but oscillating → raise D to damp the oscillation → raise I last to kill the remaining steady offset.

<table align="center">
<tr>
<td align="center" width="1320">
<br/>
<sub><b>Step response at each tuning stage — turn_control, 90° target</b></sub>
</td>
</tr>
</table>

<table align="center">
<tr>
<td align="center" width="1320">
<br/>
<sub><b>Step response at each tuning stage — forward_control, 8° drift correction</b></sub>
</td>
</tr>
</table>

---

### 5.7 Telemetry & Debug Tool — Baggy

<table align="center">
<tr>
<td align="center" width="720">
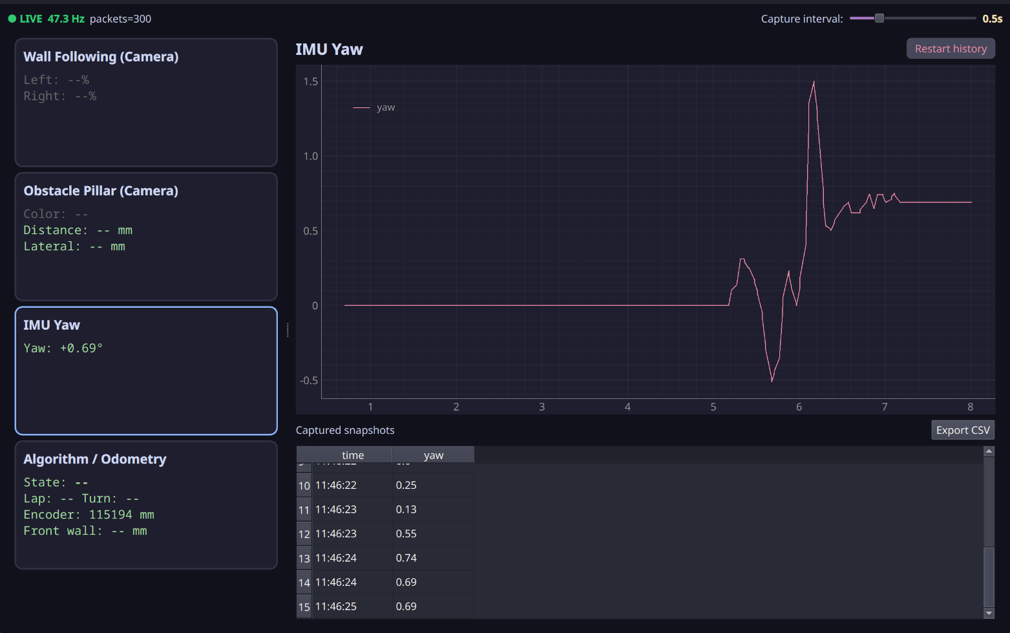
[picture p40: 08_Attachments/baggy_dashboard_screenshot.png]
<br/>
<sub><b>Baggy — our real-time telemetry dashboard</b></sub>
</td>
</tr>
</table>

The ESP32 streams live sensor and state data over Wi-Fi UDP — yaw, ToF readings, encoder distance, current state machine state, lap and turn counts — and Baggy renders it in real time so we can watch a run unfold from the sideline instead of guessing after the fact from serial logs.

*Full write-up once the tool is stable.*

---

## 6. The Vehicle

Six views of the assembled vehicle. Click any image for the full-resolution version.

<table align="center">
<tr>
<td align="center" width="330">
<br/>
<sub><b>Front</b></sub>
</td>
<td align="center" width="330">
<br/>
<sub><b>Back</b></sub>
</td>
<td align="center" width="330">
<br/>
<sub><b>Left side</b></sub>
</td>
</tr>
<tr>
<td align="center" width="330">
<br/>
<sub><b>Right side</b></sub>
</td>
<td align="center" width="330">
<br/>
<sub><b>Top</b></sub>
</td>
<td align="center" width="330">
<br/>
<sub><b>Bottom</b></sub>
</td>
</tr>
</table>

---

## 7. Videos

### Open Challenge

*≥ 30 seconds of autonomous driving, uncut.*

<table align="center">
<tr>
<td align="center" width="700">
<a href="https://youtu.be/OPEN_CHALLENGE_LINK_HERE">

</a><br/>
<sub><b>▶ Open Challenge run — click to watch on YouTube</b></sub>
</td>
</tr>
</table>

---

### Obstacle Challenge

*≥ 30 seconds of autonomous driving with pillar avoidance, uncut.*

<table align="center">
<tr>
<td align="center" width="700">
<a href="https://youtu.be/OBSTACLE_CHALLENGE_LINK_HERE">

</a><br/>
<sub><b>▶ Obstacle Challenge run — click to watch on YouTube</b></sub>
</td>
</tr>
</table>

---

## 8. Repository Map

| Folder | Contents |
|---|---|
| [`00_Research`](00_Research) | The reasoning behind every decision — component selection criteria, mechanical calculations, comparisons |
| [`01_Hardware`](01_Hardware) | Final bill of materials, power architecture, and wiring — what was actually built |
| [`02_Software`](02_Software) | ESP32 firmware source code and module documentation |
| [`03_Models`](03_Models) | All 16 custom 3D-printed parts: STL files, dimensioned drawings, and design documentation |
| [`04_PCB`](04_PCB) | Full circuit schematic |
| [`05_t_photos`](05_t_photos) | Team photos — official, casual, and individual member portraits |
| [`06_v-photos`](06_v-photos) | Vehicle photos — all six required views (front, back, left, right, top, bottom) |
| [`07_videos`](07_videos) | Competition run videos — Open Challenge and Obstacle Challenge |
| [`08_Attachments`](08_Attachments) | Logo, drawing thumbnails, diagrams, and supporting images used across the documentation |

---

## 9. Build & Run

*Build, compile, and upload instructions will be added here once the firmware and vision pipeline reach a stable release.*

---

## 10. Behind the Build

A few photos from the process — the practice mat, the pillars, and the robot itself mid-build.

---

**The practice mat**

Our university has an official WRO mat we could test on — in theory. In practice, getting there every day wasn't something we could count on. Road closures and checkpoints across the West Bank can turn a normal commute into hours of uncertainty, or make it impossible altogether, so building a testing schedule around "just drive to uni" wasn't realistic.

<table align="center">
<tr>
<td align="center" width="500">
<br/>
<sub><b>What a normal commute can look like here</b></sub>
</td>
</tr>
</table>

So we built our own. Cheap boards, spray paint, and a lot of newspaper to protect the floor — the same mat, made at home, out of whatever we could actually get our hands on.

<table align="center">
<tr>
<td align="center" width="330">
<br/>
<sub><b>Boards and spray paint — the start of it</b></sub>
</td>
<td align="center" width="330">
<br/>
<sub><b>Border strips, freshly painted</b></sub>
</td>
<td align="center" width="330">
<br/>
<sub><b>Still drying, late on the terrace</b></sub>
</td>
</tr>
</table>

<table align="center">
<tr>
<td align="center" width="330">
<br/>
<sub><b>Rolling frame, ready to move</b></sub>
</td>
<td align="center" width="330">
<br/>
<sub><b>Track border laid out on the terrace</b></sub>
</td>
<td align="center" width="330">
<br/>
<sub><b>Test pillars placed for size</b></sub>
</td>
</tr>
</table>

---

**The workbench**

This is where the actual engineering happens — not in the documentation, here. Every part on this desk went through the same loop: measure it, print or cut it, test-fit it, and almost always redo it. Half-finished pillars next to calipers, wheels waiting to be wired, a soldering iron that never really gets put away.

<table align="center">
<tr>
<td align="center" width="500">
<br/>
<sub><b>Mid-build — pillars, wheels, tools, and a couple of water bottles</b></sub>
</td>
</tr>
</table>

---

**The robot**

The first real test on our own mat is what changed things. A calculation on paper is one thing — watching the robot actually try to turn, actually try to see a pillar, on the exact surface and dimensions we'd built, is another. Some assumptions from the spec sheets didn't survive contact with the real mat, and the chassis went through a redesign because of it. What's shown across this README is the result of that — not the first version we built, but the one that came out the other side of testing on the thing in the photos above.

<table align="center">
<tr>
<td align="center" width="500">
<br/>
<sub><b>Pi 5 and ESP32 stacked up top, wired in</b></sub>
</td>
</tr>
</table>

---

<p align="center"><em>More to come as the build progresses.</em></p>

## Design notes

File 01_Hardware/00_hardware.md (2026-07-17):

# Hardware

Overview of the robot's electromechanical design. This folder documents the final, built hardware. For the reasoning and calculations behind each decision, see [`00_Research`](../00_Research).

---

## Table of Contents

- [1. Summary](#1-summary)
- [2. Documents in This Folder](#2-documents-in-this-folder)
- [3. Design Reasoning — Research References](#3-design-reasoning--research-references)

---

## 1. Summary

The vehicle is a rear-wheel-drive, Ackermann-steered platform built around a dual-computer architecture: an ESP32 handles real-time sensing and motor/servo control, while a Raspberry Pi 5 is reserved for vision processing. Full component list, power design, and pinout are documented in this folder.

| Subsystem | Summary |
|---|---|
| Drive | Single JGB37-520 DC motor, rear axle, via TB6612FNG |
| Steering | MG996R servo, Ackermann front geometry |
| Sensing | 3× VL53L0X (front/left/right), BNO055 IMU, hall-effect encoder |
| Compute | ESP32-DEVKITC-32D (control) + Raspberry Pi 5 (vision) |
| Power | 3S Li-Ion, dual isolated MP1584EN rails (5V logic, 6V servo) |

---

## 2. Documents in This Folder

| File | Contents |
|---|---|
| [`01_bill-of-materials.md`](01_bill-of-materials.md) | Final component list, grouped by subsystem |
| [`02_power-architecture.md`](02_power-architecture.md) | Rail structure, current budget, isolation rationale |
| [`03_wiring.md`](03_wiring.md) | Full GPIO pinout, I2C buses, XSHUT sequencing |

---

## 3. Design Reasoning — Research References

Every hardware decision above was driven by a calculation or comparison documented in `00_Research`:

| Decision | Research Document |
|---|---|
| Drive motor torque/speed requirement | [`03_components_selection/01_motor-selection-criteria.md`](../00_Research/03_components_selection/01_motor-selection-criteria.md) |
| Steering servo torque requirement | [`03_components_selection/02_servo-torque-requirement.md`](../00_Research/03_components_selection/02_servo-torque-requirement.md) |
| Decoupling/bulk capacitor and pull-resistor sizing | [`03_components_selection/03_passive-components.md`](../00_Research/03_components_selection/03_passive-components.md) |
| Differential vs. solid axle drivetrain | [`04_mechanical/01_Differential.md`](../00_Research/04_mechanical/01_Differential.md) |
| Ackermann steering geometry | [`04_mechanical/02_ackermann-steering.md`](../00_Research/04_mechanical/02_ackermann-steering.md) |

This folder documents **what was built**. The research folder documents **why it was built that way**.

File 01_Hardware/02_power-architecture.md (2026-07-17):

# Power Architecture

This document describes the actual power distribution design of the robot: rail structure, current budget, and isolation strategy.

---

## Table of Contents

- [1. Overview](#1-overview)
- [2. Rail Structure](#2-rail-structure)
- [3. Current Budget](#3-current-budget)
- [4. Why the Servo Rail Is Isolated](#4-why-the-servo-rail-is-isolated)
- [5. Capacitor Placement](#5-capacitor-placement)

---

## 1. Overview

<p align="center">
  dual rail power architecture
</p>

The robot runs on a single 3S Li-Ion battery (11.1V nominal) feeding two independent buck converters. Each converter powers a separate rail so that current spikes on one rail cannot affect the other.

```
3S Li-Ion (11.1V)
      │
      ├── MP1584EN #1 → 5V rail  → ESP32, sensors, logic
      │
      └── MP1584EN #2 → 6V rail  → MG996R servo only
```

---

## 2. Rail Structure

<p align="center">
  buck converter block diagram
</p>

| Rail | Voltage | Powers |
|---|---|---|
| Logic rail | 5V | ESP32, BNO055, VL53L0X ×3, encoder |
| Servo rail | 6V | MG996R steering servo only |
| Motor rail | 11.1V (direct from battery) | JGB37-520 via TB6612FNG |

The drive motor is powered directly from the battery through the TB6612FNG — it does not pass through either buck converter, since the motor driver handles its own switching.

---

## 3. Current Budget

| Load | Typical | Peak (stall) |
|---|---|---|
| ESP32 | 160 mA | 240 mA |
| BNO055 | 12 mA | — |
| VL53L0X ×3 | 60 mA (20 mA each) | — |
| Encoder | < 5 mA | — |
| **Logic rail total** | **~240 mA** | **~300 mA** |
| MG996R servo | 500 mA | 2.5 A |
| **Servo rail total** | **500 mA** | **2.5 A** |
| JGB37-520 motor | 450 mA | 1.2 A |

The servo's 2.5A stall spike is the dominant transient in the system — over 8× the entire logic rail's typical draw. This spike is the primary reason for rail isolation (see Section 4).

---

## 4. Why the Servo Rail Is Isolated

If the servo shared a rail with the ESP32 and sensors, a stall event (servo hitting mechanical limit or high steering load) would pull 2.5A instantaneously. This causes the shared rail voltage to sag, which can:

- Brown-out reset the ESP32 mid-operation
- Cause I2C bus errors on the sensor bus
- Corrupt in-progress control loop state

By giving the servo its own MP1584EN converter, a stall event only sags the servo rail — the logic rail stays stable and the ESP32 keeps running.

> This is not about voltage difference (5V vs 6V) — it is about current isolation. Even if the servo ran at 5V, it would still need its own regulator to prevent stall transients from affecting logic.

---

## 5. Capacitor Placement

Bulk and decoupling capacitor sizing follows the calculations in [`03_passive-components.md`](../00_Research/03_components_selection/03_passive-components.md):

- **100 nF decoupling** at every IC's VCC pin (ESP32, BNO055, each VL53L0X)
- **100–470 µF bulk capacitor** at each MP1584EN output, closest to the highest-current load on that rail
- Servo rail bulk capacitor sized toward the upper end (470 µF) given the 2.5A stall spike

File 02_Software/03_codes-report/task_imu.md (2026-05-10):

# task_imu

## Overview

`task_imu` is responsible for periodically reading yaw from the BNO055 IMU and publishing it to a shared state protected by a mutex. It is the sole writer of the yaw state. Any other task that needs yaw calls `yaw_read()` and gets a consistent snapshot.

---

## Shared State

The following variables are module-private and only accessible through the read/write API:

| Variable | Type | Description |
|---|---|---|
| `g_yaw` | `float` | Latest yaw angle in degrees, relative, wrapped \[-180, 180\] |
| `g_yaw_valid` | `bool` | True once the first successful read has occurred |
| `g_yaw_us` | `int64_t` | Timestamp of the last successful write, in microseconds |

> These variables are `volatile` to prevent the compiler from caching them across task context switches.

---

## Functions

### `imu_task_start(bno055_imu_t *imu, SemaphoreHandle_t mutex)`

Entry point called from `app_main`. Stores the IMU handle and mutex pointer into module-level statics, then spawns the `imu_task` FreeRTOS task.

Must be called after:
- `bno_setup()` has succeeded
- `yaw_mutex` has been created by `init_mutexes()`

---

### `imu_task(void *arg)` *(static)*

The FreeRTOS task function. Runs on a fixed period defined by `IMU_PERIOD_MS` (10 ms).

Each cycle:
1. Calls `bno_read_yaw_rel_deg()` to get the latest filtered relative yaw from the BNO055.
2. If the result is not `NAN`, calls `yaw_write()` to update shared state.
3. If the result is `NAN`, logs a warning and skips the write — the previous valid value is preserved.
4. Sleeps until the next period using `vTaskDelayUntil()`, which keeps the period accurate regardless of how long the read takes.

**Warning:** If `bno_read_yaw_rel_deg()` consistently returns `NAN`, `g_yaw_valid` will never be set and consumers will see `age_us = INT64_MAX`.

---

### `yaw_write(float yaw_deg)` *(static)*

Internal writer. Takes `s_mutex`, updates `g_yaw`, `g_yaw_valid`, and `g_yaw_us`, then releases the mutex. Never called from outside the file.

---

### `yaw_read(float *yaw_deg, bool *ok, int64_t *age_us)`

Public reader. Copies the shared state under the mutex into local variables, then assigns to the output pointers after releasing the lock — minimizing time spent holding it.

`age_us` is computed as `now - g_yaw_us`. If `g_yaw_valid` is false, `age_us` is set to `INT64_MAX` as a sentinel so the caller can detect a stale or uninitialized state.

Returns early (no-op) if the mutex is not initialized or any output pointer is NULL.

---

### `yaw_zero(void)`

Delegates to `bno_zero_yaw()` on the stored IMU handle. Resets the relative yaw reference to the current heading and clears the filter buffer. Safe to call from any task.

---

## Timing

| Parameter | Value |
|---|---|
| Period | 10 ms |
| Stack size | 2048 bytes |
| Priority | 5 |

---

## Data Flow

```
BNO055 hardware
      │
      ▼
bno_read_yaw_rel_deg()
      │
      ▼
  imu_task  ──[yaw_mutex]──► g_yaw / g_yaw_valid / g_yaw_us
                                        │
                                        ▼
                                   yaw_read()
                                        │
                                        ▼
                                  control_task
```

---

## Related

- [task_tof](task_tof.md)
- `imu_bno055.h` — BNO055 driver API
- `main.cpp` — calls `imu_task_start()`

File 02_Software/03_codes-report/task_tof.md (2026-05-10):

# task_tof

## Overview

`task_tof` periodically reads all three ToF sensors (front, left, right) and publishes their readings as a single atomic `tof_state_t` snapshot protected by a mutex. It is the sole writer of the ToF state. Any other task that needs distance data calls `tof_read()`.

---

## Shared State

All shared data is packed into a single struct:

```c
typedef struct {
    uint8_t  left_mm;
    uint16_t front_mm;
    uint8_t  right_mm;
    bool     wall_left;
    bool     wall_front;
    bool     wall_right;
    bool     front_emergency_wall;
    bool     front_warning_wall;
    bool     valid;
    int64_t  ts_us;
} tof_state_t;
```

| Field | Description |
|---|---|
| `left_mm` | Left sensor reading in mm (VL6180X, range 0–255) |
| `front_mm` | Front sensor reading in mm (VL53L0X, range 0–2000) |
| `right_mm` | Right sensor reading in mm (VL6180X, range 0–255) |
| `wall_left` | True if left distance ≤ `WALL_LEFT_MM` |
| `wall_front` | True if front distance ≤ `WALL_FRONT_MM` |
| `wall_right` | True if right distance ≤ `WALL_LEFT_MM` |
| `front_warning_wall` | True if front distance ≤ `WALL_WARNING_MM` — slow down |
| `front_emergency_wall` | True if front distance ≤ `WALL_EMERGENCY_MM` — stop immediately |
| `valid` | True once the first successful read has occurred |
| `ts_us` | Timestamp of the last successful write in microseconds |

> The boolean flags are computed inside `tof_write()` before the mutex is taken, so the lock is held only for the struct copy — not for the threshold comparisons.

---

## Threshold Defines

| Define | Value | Meaning |
|---|---|---|
| `WALL_LEFT_MM` | 150 | Side wall detection threshold |
| `WALL_FRONT_MM` | 200 | Front wall detection threshold |
| `WALL_WARNING_MM` | 150 | Front warning zone |
| `WALL_EMERGENCY_MM` | 80 | Front emergency stop zone |

**Note:** These thresholds are starting values and will need tuning on the actual track.

---

## Functions

### `tof_task_start(ToF *tof, SemaphoreHandle_t mutex)`

Entry point called from `app_main`. Stores the ToF object pointer and mutex into module-level statics, then spawns the `tof_task` FreeRTOS task.

Must be called after:
- `tof.tof_setup()` has succeeded
- `tof_mutex` has been created by `init_mutexes()`

---

### `tof_task(void *arg)` *(static)*

The FreeRTOS task function. Runs on a fixed period defined by `TOF_PERIOD_MS` (20 ms).

Each cycle:
1. Calls `readRangeMMFiltered()` on all three sensors sequentially.
2. If all three reads return `ESP_OK`, calls `tof_write()` to update shared state.
3. If any read fails, logs a warning with individual error codes and skips the write — the previous valid snapshot is preserved.
4. Sleeps until the next period using `vTaskDelayUntil()`.

**Note:** The three sensor reads are sequential, not parallel. At 20 ms period with filtered reads this is acceptable. If latency becomes an issue this can be revisited.

---

### `tof_write(uint16_t front, uint8_t left, uint8_t right)` *(static)*

Internal writer. Builds a complete `tof_state_t` locally — raw values, all boolean flags, validity, and timestamp — then takes `s_mutex` only to copy the finished struct into `g_state`. Lock time is one struct assignment.

---

### `tof_read(tof_state_t *out)`

Public reader. Takes the mutex, copies `g_state` into `*out`, then releases. Returns `false` if the mutex is not initialized or `out` is NULL.

The caller gets a full atomic snapshot — no partial reads possible.

---

## Timing

| Parameter | Value |
|---|---|
| Period | 20 ms |
| Stack size | 3072 bytes |
| Priority | 5 |

> Stack is larger than `task_imu` because the ToF object methods have deeper call chains than the IMU read.

---

## Data Flow

```
VL53L0X (front)
VL6180X (left)   ──► tof_task ──[builds tof_state_t]──[tof_mutex]──► g_state
VL6180X (right)                                                          │
                                                                         ▼
                                                                    tof_read()
                                                                         │
                                                                         ▼
                                                                   control_task
```

---

## Related

- [task_imu](task_imu.md)
- `ToF.h` — ToF manager class
- `VL53L0X.h` — Front sensor driver
- `VL6180X.h` — Side sensor driver
- `main.cpp` — calls `tof_task_start()`

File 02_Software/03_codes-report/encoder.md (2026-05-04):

# Encoder — Design Report

A concise record of the design decisions behind `encoder.c`, written for a single hall-effect encoder on the JGB37-520 motor, used to measure distance traveled on an Ackermann-steered platform.

---

## Table of Contents

- [Single Encoder Architecture](#single-encoder-architecture)
- [Interrupt-Driven Counting](#interrupt-driven-counting)
- [IRAM Placement](#iram-placement)
- [Volatile Ticks](#volatile-ticks)
- [Distance Calculation](#distance-calculation)
- [Edge Detection Choice](#edge-detection-choice)
- [What Was Removed From the Original](#what-was-removed-from-the-original)

---

## Single Encoder Architecture

The original micromouse code used two encoders — one per drive wheel — for odometry and differential speed control. On an Ackermann platform with a single rear drive motor, one encoder on the motor shaft is sufficient. There is no per-side tracking needed; the single encoder measures how far the vehicle has traveled along its driven axis.

---

## Interrupt-Driven Counting

The encoder ISR is triggered on every rising edge of the encoder signal. Each trigger increments a tick counter. This approach offloads all counting work from the main loop — the main task never needs to poll the pin, it simply reads the counter whenever it needs a distance snapshot.

The counter is `int32_t`, giving a range of ±2.1 billion ticks before overflow. At the JGB37-520's gear ratio and wheel diameter, this corresponds to a travel distance far exceeding any practical concern.

---

## IRAM Placement

The ISR is marked `IRAM_ATTR`, placing it in internal RAM rather than flash. This ensures the interrupt handler executes immediately even if the flash cache is busy at the moment the interrupt fires. Without this, the ISR could stall for an unpredictable number of cycles, causing missed ticks at high motor speeds.

---

## Volatile Ticks

The `ticks` field in the encoder struct is declared `volatile`. This tells the compiler it must not cache the value in a CPU register between reads — it must always fetch it from memory. Without `volatile`, the compiler could legally optimize a read loop into reading the value once and reusing it, never seeing updates written by the ISR.

`IRAM_ATTR` and `volatile` solve different problems and are both required:

| Keyword | Scope | Solves |
|---|---|---|
| `IRAM_ATTR` | Linker | ISR lives in IRAM, executes without cache dependency |
| `volatile` | Compiler | Main code always reads the latest value from memory |

---

## Distance Calculation

Distance is derived from tick count using two hardware constants:

```
MM_PER_TICK = (π × wheel_diameter) / (CPR × gear_ratio)
distance    = ticks × MM_PER_TICK
```

These constants are defined in the header and must be verified against the physical hardware before use:

| Constant | Source |
|---|---|
| `ENCODER_CPR` | Motor datasheet — counts per motor shaft revolution |
| `GEAR_RATIO` | Motor label — printed as e.g. 1:30 |
| `WHEEL_DIAMETER_MM` | Physical measurement of the mounted wheel |

An incorrect value in any of these three will silently produce wrong distance readings with no compile-time warning. They should be validated by manually rotating the wheel a known distance and comparing the reported value.

---

## Edge Detection Choice

The ISR triggers on `GPIO_INTR_POSEDGE` — rising edges only. This counts one tick per electrical cycle of the encoder signal.

Switching to `GPIO_INTR_ANYEDGE` would trigger on both rising and falling edges, doubling the effective resolution without any hardware change. This is a straightforward upgrade if finer distance granularity is needed later, requiring only a one-line change in `encoder_setup()` and a corresponding update to `ENCODER_CPR`.

---

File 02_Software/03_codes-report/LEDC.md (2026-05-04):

# LEDC — LED Control (PWM) Peripheral

The ESP32's LEDC peripheral is a dedicated PWM signal generator. Despite the name, it is general-purpose — it can drive anything that needs a PWM signal: LEDs, DC motors, servos, buzzers. It provides up to 8 independent channels, each capable of outputting a configurable frequency and duty cycle on any GPIO pin.

---

## Table of Contents

- [What LEDC Actually Is](#what-ledc-actually-is)
- [Architecture: Timers and Channels](#architecture-timers-and-channels)
- [Speed Modes](#speed-modes)
- [Clock Sources](#clock-sources)
- [The Frequency–Resolution Tradeoff](#the-frequencyresolution-tradeoff)
  - [The Math](#the-math)
  - [Tradeoff Table](#tradeoff-table)
  - [Practical Limits for ESP32](#practical-limits-for-esp32)
- [Timer Configuration](#timer-configuration)
- [Channel Configuration](#channel-configuration)
- [Changing the PWM Signal at Runtime](#changing-the-pwm-signal-at-runtime)
  - [Software Duty Update](#software-duty-update)
  - [Hardware Fading](#hardware-fading)
- [Duty Cycle Range and the Overflow Warning](#duty-cycle-range-and-the-overflow-warning)
- [Practical Application: Motor and Servo](#practical-application-motor-and-servo)
- [Common Pitfalls](#common-pitfalls)

---

## What LEDC Actually Is

LEDC generates a **PWM (Pulse Width Modulation)** signal — a square wave that alternates between high and low at a fixed frequency, with a programmable ratio of high-to-low time called the **duty cycle**.

<p align="center">
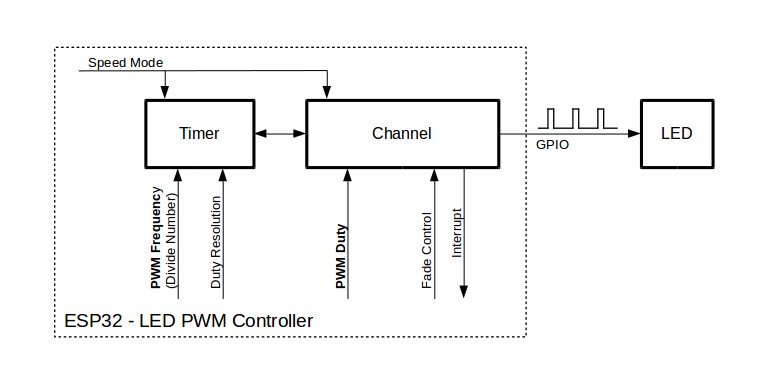
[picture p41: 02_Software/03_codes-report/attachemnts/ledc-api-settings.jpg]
PWM duty cycle illustration
  
</p>

A 50% duty cycle means the signal is high for exactly half the period and low for the other half. A 75% duty cycle means it is high for three-quarters of each period. This is how LEDC controls intensity, speed, or position — not by changing voltage, but by changing how long the signal stays high within each cycle.

The peripheral is called "LED Control" because that is its primary intended use in Espressif's product line. The hardware is identical for any PWM application.

---

## Architecture: Timers and Channels

LEDC is structured in two layers:

```
Clock Source
    └── Timer (sets frequency + resolution)
            └── Channel (sets duty cycle, linked to a GPIO pin)
```

- **Timers** control the time base — they define the PWM frequency and how many bits of resolution are available for the duty cycle.
- **Channels** ride on top of a timer — they define what fraction of each timer period the signal stays high, and which GPIO the signal outputs on.

On ESP32, there are **4 timers** and **8 channels** per speed mode group, giving 8 usable channels total in the common case. Multiple channels can share one timer, meaning they share the same frequency but have independent duty cycles.

| Resource | Count (ESP32) |
|---|---|
| High speed timers | 4 |
| High speed channels | 8 |
| Low speed timers | 4 |
| Low speed channels | 8 |
| Usable channels (typical) | 8 |

**LEDC_CHANNEL_0** in **LEDC_HIGH_SPEED_MODE** and **LEDC_CHANNEL_0** in **LEDC_LOW_SPEED_MODE** are two different physical channels. The index just identifies the channel within its group.

---

## Speed Modes

The ESP32 LEDC peripheral has two speed modes: **high speed** and **low speed**. This distinction is unique to the original ESP32 — all newer variants (S2, S3, C3, C6, H2, etc.) only have low speed mode.

| Mode | Duty Cycle Update | Mechanism | Availability |
|---|---|---|---|
| High speed | Glitch-free, automatic | Hardware applies change at next timer overflow | ESP32 only |
| Low speed | Requires software trigger | Driver calls update in the background | All ESP32 variants |

**High speed mode** means that when you change the duty cycle, the hardware waits for the current PWM period to complete before applying the new value. There is no partial pulse — no glitch. The transition is invisible to the connected device.

**Low speed mode** requires the driver to explicitly trigger the update. The ESP-IDF handles this automatically when you call `ledc_update_duty`, but the update may apply mid-period, causing a single irregular pulse at the moment of change. For motors and servos this is imperceptible.

> **Practical note:** For this project's use case (servo steering, DC motor speed), both modes are functionally equivalent. The glitch difference is only relevant in precision LED dimming or high-frequency signal generation.

---

## Clock Sources

The timer needs a clock source to count from. The selected clock source sets the upper bound on how high a PWM frequency can be configured.

### ESP32 Clock Sources

| Clock | Frequency | Speed Mode | Notes |
|---|---|---|---|
| APB_CLK | 80 MHz | High / Low | Default, highest frequency capability |
| REF_TICK | 1 MHz | High / Low | DFS compatible — stays accurate during CPU frequency scaling |
| RC_FAST_CLK | ~8 MHz | Low only | Light-sleep compatible, but frequency is approximate |

**`LEDC_AUTO_CLK`** in the configuration tells the driver to select the best available source automatically. This is the correct default for most applications.

> **Important:** On the standard ESP32, each timer has its own clock mux, so different timers can use different sources. On some other variants, all timers share one clock source — mixing clock sources is impossible on those chips.

### Why Clock Source Matters

The maximum PWM frequency achievable is bounded by:

```
f_max = clock_source_frequency / 2^resolution
```

Using RC_FAST_CLK (8 MHz) at 10-bit resolution gives a maximum of only ~7.8 kHz. If you need 20 kHz for a motor, you must use APB_CLK (80 MHz).

---

## The Frequency–Resolution Tradeoff

This is the most important concept in LEDC configuration. **Frequency and duty resolution are not independent — they share the same timer clock budget.**

### The Math

The timer generates PWM by counting clock ticks. One full PWM period consumes exactly `2^resolution` clock ticks. Therefore:

```
frequency = clock_source / 2^resolution

or equivalently:

max_resolution = log2(clock_source / frequency)
```

The timer is a hardware counter that increments by 1 on every clock tick. It counts from `0` up to `2^resolution − 1`, then resets to `0` and begins again. One full count-and-reset cycle is exactly one PWM period.

The duty cycle is controlled by a **compare register**. The hardware continuously compares the running counter against this value:

- Counter **below** compare value → output is **HIGH**
- Counter **above** compare value → output is **LOW**

```
Counter:  0 ──────────────────► 2^resolution
Output:   HIGH ──────────┐      LOW      ┌──► (next period)
                         └───────────────┘
                      compare value
```

Setting the compare value to `512` on a 10-bit timer (which counts to 1023) produces exactly 50% duty cycle. Setting it to `256` produces 25%, and so on.

The frequency follows directly from how long one full count takes:

This is where the tradeoff originates physically — higher resolution means more ticks per period, which means a longer period, which means a lower frequency. You cannot increase both simultaneously because they are both consuming the same clock budget.

Using APB_CLK at 80 MHz:

| Desired Frequency | Max Resolution | Duty Steps |
|---|---|---|
| 1 Hz | ~26 bit | 67 million |
| 100 Hz | ~19 bit | 524,288 |
| 1 kHz | ~16 bit | 65,536 |
| 5 kHz | ~13 bit | 8,192 |
| 20 kHz | ~11 bit | 2,048 |
| 78 kHz | ~10 bit | 1,024 |
| 312 kHz | ~8 bit | 256 |
| 40 MHz | 1 bit | 2 (50% fixed) |

### Tradeoff Table

| Increase | Effect |
|---|---|
| Higher frequency | Lower max resolution → coarser duty cycle steps |
| Higher resolution | Lower max frequency → slower PWM period |

Trying to configure an invalid combination (e.g., 20 MHz at 3-bit) causes the driver to log an error and refuse the configuration:

```
E (196) ledc: requested frequency and duty resolution cannot be achieved,
try reducing freq_hz or duty_resolution. div_param=128
```

### Practical Limits for ESP32

The LEDC driver includes a helper `ledc_find_suitable_duty_resolution()` that computes the maximum resolution for a given clock and desired frequency. You can also compute it manually using the formula above.

At 20 kHz (motor PWM): `log2(80,000,000 / 20,000)` = `log2(4000)` ≈ **11.96 → 11-bit max**. Using 10-bit is safe and leaves headroom.

At 50 Hz (servo PWM): `log2(80,000,000 / 50)` = `log2(1,600,000)` ≈ **20.6 → 20-bit max**. Using 16-bit is safe and gives extremely fine pulse width resolution.

---

## Timer Configuration

The timer is configured through `ledc_timer_config_t`. It defines the frequency and resolution for any channel that binds to it. Timer configuration must happen **before** channel configuration — the ESP-IDF documentation explicitly recommends this ordering so the PWM signal appears at the correct frequency from the first moment the GPIO activates.

| Field | Purpose |
|---|---|
| `speed_mode` | High or low speed group |
| `timer_num` | Which of the 4 timers (TIMER_0 to TIMER_3) |
| `freq_hz` | Target PWM frequency |
| `duty_resolution` | Bit depth of duty cycle (determines step count) |
| `clk_cfg` | Clock source — use `LEDC_AUTO_CLK` by default |

A timer can be released when no longer needed by setting the `deconfigure` flag in the config struct and calling `ledc_timer_config` again.

> **Global register warning:** Timer settings are hardware registers — they are global across the entire firmware. If two files configure `LEDC_TIMER_0` with different settings, whichever runs last wins. All timer/channel assignments must be centralized in a single header to avoid conflicts.

---

## Channel Configuration

A channel binds a timer to a GPIO and sets an initial duty cycle. From the moment `ledc_channel_config` is called, the PWM signal begins outputting on the specified pin.

| Field | Purpose |
|---|---|
| `speed_mode` | Must match the bound timer's speed mode |
| `channel` | Which of the 8 channels (CHANNEL_0 to CHANNEL_7) |
| `timer_sel` | Which timer this channel uses |
| `gpio_num` | Output GPIO pin |
| `duty` | Initial duty cycle value (0 to 2^resolution − 1) |
| `hpoint` | Rising edge offset within the period — almost always 0 |
| `intr_type` | Interrupt on fade end — use `LEDC_INTR_DISABLE` unless fading |

`hpoint` deserves a brief explanation. Normally all channels driven by the same timer start their high pulse at the same moment within the period. `hpoint` shifts the rising edge of a specific channel forward in time. This can reduce instantaneous current spikes when many PWM devices switch simultaneously — not relevant for one or two channels, but useful in larger systems.

---

## Changing the PWM Signal at Runtime

### Software Duty Update

Changing the duty cycle at runtime is a two-step process:

1. **Write the new value** with `ledc_set_duty` — this stages the value but does not apply it yet.
2. **Commit it** with `ledc_update_duty` — this triggers the hardware to pick up the new value.

This separation exists because the update is not instantaneous at the hardware level. The two-step pattern ensures the new duty cycle takes effect in a controlled way rather than potentially corrupting an in-progress cycle.

> **Hardware overflow warning:** On ESP32, if you select the maximum resolution for a timer, the duty cycle value must not be set to exactly `2^resolution`. Setting duty to `1024` on a 10-bit timer causes the internal hardware counter to overflow and produce an incorrect output. Always cap the maximum value at `(2^resolution) − 1` = 1023 for 10-bit.

### Hardware Fading

LEDC has a built-in fade engine that smoothly transitions the duty cycle from one value to another without any CPU involvement. This is an interrupt-driven hardware feature.

To use it, the fade service must be installed once with `ledc_fade_func_install`. After that, fades are configured with one of the following:

| Function | Description |
|---|---|
| `ledc_set_fade_with_time` | Transition to target duty over a specified duration in ms |
| `ledc_set_fade_with_step` | Transition in fixed increments at a fixed interval |
| `ledc_set_fade` | Manual control over step size and cycle count |

After configuring, `ledc_fade_start` begins the transition. It can run in blocking mode (function returns only when fade completes) or non-blocking mode (returns immediately, fade continues in background).

> On ESP32, a fade in progress cannot be stopped before it reaches its target. On other variants, `ledc_fade_stop` can abort it.

A callback can be registered via `ledc_cb_register` to receive a notification when a fade finishes. The callback and any functions it calls must be placed in IRAM using `IRAM_ATTR`, since the callback runs from within an ISR.

---

## Duty Cycle Range and the Overflow Warning

The valid duty cycle range for a channel is `0` to `(2^resolution) − 1`. This maps directly to 0% to 100% of the PWM period.

| Resolution | Max Duty Value | % Step Size |
|---|---|---|
| 8-bit | 255 | ~0.39% |
| 10-bit | 1023 | ~0.098% |
| 13-bit | 8191 | ~0.012% |
| 16-bit | 65535 | ~0.0015% |

Setting duty to exactly `2^resolution` on ESP32 causes a hardware counter overflow and corrupts the output signal. The driver does not catch this — it is the programmer's responsibility to clamp values below the maximum.

---

## Practical Application: Motor and Servo

The two devices have very different PWM requirements, which is why they must use separate timers.

| Parameter | Servo | DC Motor (via TB6612FNG) |
|---|---|---|
| Frequency | 50 Hz | 20 kHz |
| Resolution | 16-bit | 10-bit |
| Timer | LEDC_TIMER_0 | LEDC_TIMER_1 |
| Channel | LEDC_CHANNEL_0 | LEDC_CHANNEL_1 |
| Duty interpretation | Pulse width (500–2500 µs) | Speed percentage (0–100%) |
| Why this frequency | Servo protocol standard | Above 20 kHz human hearing threshold |

**Servo frequency reasoning:** Standard hobby servos use a 20 ms period (50 Hz). The position is encoded not in the duty cycle percentage, but in the absolute pulse width within that period. A 1500 µs pulse is center, 500 µs is one extreme, 2500 µs is the other. At 50 Hz and 16-bit resolution, each step is approximately 0.3 µs — far finer than any servo can mechanically respond to.

**Motor frequency reasoning:** The TB6612FNG PWM input switches the internal H-bridge MOSFETs. If the switching frequency falls in the 20 Hz–20 kHz audible range, the motor coils physically vibrate at that frequency and produce an audible whine. Running at 20 kHz pushes this above human hearing. At 20 kHz, 10-bit resolution gives 1024 speed steps (~0.1% per step), which is more than sufficient for a drive motor.

**Why they cannot share a timer:** A single timer can only have one frequency. A timer set to 50 Hz cannot simultaneously provide 20 kHz for a motor. They must use separate timers.

---

## Common Pitfalls

| Pitfall | Consequence | Fix |
|---|---|-----|
| Duty set to exactly `2^resolution` | Hardware counter overflow, corrupted output | Cap at `(2^resolution) − 1` |
| Two files configure the same timer with different settings | Last write wins, one device gets wrong frequency | Centralize all timer/channel definesone header |
| Calling `ledc_set_duty` without `ledc_update_duty` | New value staged but never applied, output unchanged | Always call both in sequence |
| Motor PWM frequency in audible range (20 Hz–20 kHz) | Audible coil whine | Use ≥ 20 kHz |
| Using RC_FAST_CLK for precise frequency output | Output frequency may be inaccurate — no calibration on most variants | Use APB_CLK (80 MHz) for precision |
| Fade callback not placed in IRAM | Crash or undefined behavior when callback fires from ISR context | Add `IRAM_ATTR` to callback and any functions it calls |
| Multiple channels sharing one timer with different desired frequencies | Impossible — all channels on a timer share its frequency | Use a separate timer per frequency requirement |

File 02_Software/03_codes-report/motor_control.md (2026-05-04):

# Motor Control — Design Report

A concise record of the design decisions behind `motor_control.c`, written for the TB6612FNG driving a single JGB37-520 DC motor on an Ackermann-steered platform.

---

## Table of Contents

- [Single Motor Architecture](#single-motor-architecture)
- [PWM Configuration Choices](#pwm-configuration-choices)
- [STBY as Enable/Disable](#stby-as-enabledisable)
- [Brake vs Coast](#brake-vs-coast)
- [Public API Design](#public-api-design)
- [What Was Removed From the Original](#what-was-removed-from-the-original)

---

## Single Motor Architecture

The original micromouse code controlled two independent motors for differential steering. The WRO platform uses Ackermann steering — a servo handles direction, and a single rear motor handles speed. There is no per-side speed differential needed, so the entire right-motor half of the driver was removed. The TB6612FNG has two channels; only channel A is wired and used.

---

## PWM Configuration Choices

| Parameter | Value | Reason |
|---|---|---|
| Frequency | 20 kHz | Above human hearing — eliminates coil whine |
| Resolution | 10-bit (0–1023) | 1024 speed steps is more than enough for a drive motor |
| Timer | `LEDC_TIMER_0` | Reserved exclusively for the motor |
| Channel | `LEDC_CHANNEL_0` | Single channel, no conflicts |

The servo will use a separate timer (`LEDC_TIMER_1`) at 50 Hz and 16-bit resolution. The two devices cannot share a timer because they require different frequencies.

---

## STBY as Enable/Disable

The TB6612FNG has a standby pin (`STBY`) that disables both output channels when pulled low. The driver initializes with `STBY = 0`, meaning the motor is physically disabled at startup regardless of what the direction pins or PWM are doing. This is intentional — it prevents the motor from twitching during ESP32 boot while GPIO states are undefined.

`motor_enable()` and `motor_disable()` are exposed as part of the public API so higher-level code can arm and disarm the motor explicitly, for example at round start and on emergency stop.

---

## Brake vs Coast

The TB6612FNG supports two distinct stop behaviors:

| Mode | IN1 | IN2 | Effect |
|---|-----|-----|---|
| Brake | HIGH | HIGH | Motor terminals shorted together — back-EMF creates active braking |
| Coast | LOW | LOW | Motor terminals floating — robot rolls freely |

`stop()` maps to **brake** — the correct choice for a competition robot that needs to stop predictably at a target position. `coast()` is kept available for cases where free-rolling is intentional, such as during a controlled deceleration phase.

---

## Public API Design

The public API was intentionally kept minimal:

| Function | Purpose |
|---|---|
| `tb6612_setup()` | One-time init — GPIO, LEDC timer, LEDC channel |
| `motor_enable()` | Pull STBY high — arms the motor |
| `motor_disable()` | Pull STBY low — disarms the motor |
| `move_forward(speed)` | Drive forward at 0–100% speed |
| `move_reverse(speed)` | Drive reverse at 0–100% speed |
| `stop()` | Active brake |
| `coast()` | Free-roll stop |

Speed is expressed as a percentage (0–100) rather than raw duty counts. This keeps higher-level code readable and decoupled from the PWM resolution — if the resolution ever changes, only `pct_to_duty()` needs updating.

---

## What Was Removed From the Original

The micromouse code included functions for differential arcing, point turns, and per-side speed control. All of these were removed because they have no meaning on an Ackermann platform:

- Turning is handled entirely by the servo — the motor has no role in steering
- There is no left/right motor distinction
- `move_forward_max()`, `move_arch()`, `move_left_rotate()` and their variants are all gone

Keeping dead code would have been misleading in a documentation-scored competition.

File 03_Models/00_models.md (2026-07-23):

# Models

Every custom mechanical part of the vehicle, designed in Autodesk Fusion 360 and 3D-printed. This folder holds the print-ready files, the dimensioned engineering drawings, and the reasoning behind the design — what each part does, and why it looks the way it does.

## Contents

| Path | Description |
|---|---|
| [`stl/`](stl/) | Print-ready STL files for all 16 custom parts |
| [`drawings/`](drawings/) | Dimensioned multi-view engineering drawings (PDF), exported from Fusion 360 |
| `00_models.md` | This file — the design documentation |

---

## 1. Design Overview

The printed structure implements the two mechanical decisions explained in the [root README](../README.md#3-our-approach--drivetrain-and-steering): **rear-wheel drive through an open differential**, and **front Ackermann steering**.

A single [JGB37-520 12V gear motor](../01_Hardware/01_bill-of-materials.md) drives the rear axle through a custom bevel pinion meshing with a WLTOYS 144001 differential — an off-the-shelf RC part carried by our own printed mounts. Steering is a single MG996R servo whose custom arm drives a tie rod connecting the two steering knuckles. Everything mounts on one printed chassis plate, with raised platforms creating a second floor for the electronics.

Why these mechanisms were chosen over the alternatives (solid axle, parallel steering) is documented in the research folder:
- [`00_Research/04_mechanical/01_Differential.md`](../00_Research/04_mechanical/01_Differential.md)
- [`00_Research/04_mechanical/02_ackermann-steering.md`](../00_Research/04_mechanical/02_ackermann-steering.md)

This document covers how those decisions became physical parts.

---

## 2. The Chassis — One Plate, Three Levels

The vehicle regulations cap the footprint at 300 × 200 mm, so the layout grows *upward* instead of outward. The chassis (`main_base`, 254 × 100 mm) is a single printed plate that carries everything, with integrated columns supporting two second-floor platforms:

| Level | Part | Carries |
|---|---|---|
| Ground plate | `main_base` | Motor (mount extruded directly into the plate), differential assembly, steering knuckles, all columns |
| Front deck | `front_top` | MG996R steering servo, camera mast |
| Middle deck | `middle_top` | The main circuit board (soldered prototyping PCB — see [`04_PCB`](../04_PCB/00_PCB.md)) |
| Rear deck | `back_top` | Raspberry Pi 5 and its power bank |

Two decisions worth noting:

**The motor mount is part of the chassis, not a separate bracket.** The JGB37-520 sits in a pocket extruded directly from `main_base`. One part fewer to print, no bracket-to-chassis joint to work loose from vibration, and the motor's alignment to the differential is fixed by the geometry of a single part instead of depending on assembly accuracy.

**Electronics live on removable decks, not on the chassis.** The PCB deck and the Pi deck each come off with a few screws, so electrical work never requires touching the drivetrain — and mechanical work never requires unscrewing electronics. During a competition day, that separation is the difference between a five-minute fix and a full teardown.

The camera sits on a dedicated mast (`camera_holder`, 154.7 mm tall) mounted on the front deck, raising the [Camera Module 3](../README.md#42-vision-raspberry-pi-camera-module-3) high enough to see the track over the vehicle's own body, with the mounting frame angled downward toward the field.

---

## 3. Steering — Ackermann in Plastic

The steering linkage is a classic Ackermann trapezoid built from four printed parts: two knuckles, a tie rod, and a custom servo arm.

- Each **knuckle** (`left_knuckle`, `right_knuckle` — exact mirrors) pivots on a kingpin at the chassis, carries the front wheel axle, and has a tie-rod eye offset behind the kingpin axis.
- The **tie rod** (`ackerman_rod`) connects the two knuckle eyes, with a third linkage point at its center.
- The **servo arm** (`servo_arm`) mounts on the MG996R's splined output and drives the center of the tie rod.

The Ackermann effect comes from where the tie-rod eyes sit: they are angled inward so that the line through each kingpin and its tie-rod eye points toward the rear axle. Verified directly in CAD:

<p align="center">
  
</p>
<p align="center"><sub><b>Top view in Fusion 360 — construction lines from the steering pivots converge at the rear axle centerline, the Ackermann condition.</b></sub></p>

The result: in every turn the inner wheel steers more sharply than the outer one, all four wheels track around a common turn center, and no tire scrubs. The math behind the geometry is in [`02_ackermann-steering.md`](../00_Research/04_mechanical/02_ackermann-steering.md); the torque requirement that selected the MG996R is in [`02_servo-torque-requirement.md`](../00_Research/03_components_selection/02_servo-torque-requirement.md).

---

## 4. Drivetrain — Carrying a Differential That Wasn't Made for This Car

The WLTOYS 144001 differential is designed for a specific RC car, so the entire mounting system around it is custom:

- **`differantial_gear`** — bevel pinion pressed onto the JGB37-520 output shaft, meshing with the differential's crown gear. This is the single point where motor torque enters the axle.
- **`left_differantial_ring`, `right_differantial_ring`** — carrier rings bolted to the chassis; each seats one side of the differential by its bearing.
- **`differantial_holder`** — a 2.25 mm retaining ring glued to the right carrier ring (see [Iteration 1](#iteration-1--eliminating-differential-axial-play)).
- **`differantial_cup`** — drive cup coupling the differential output to the rear drive shaft.
- **`left_shaft_holder`, `right_shaft_holder`** — outboard bearing blocks supporting each 4 mm drive shaft near the wheel (see [Iteration 2](#iteration-2--stabilizing-the-rear-wheels)).

Torque path: motor → bevel pinion → crown gear → differential → drive cups → 4 mm shafts → rear wheels. The differential splits torque between the wheels purely mechanically, which keeps us compliant with rule 11.5 (electronic differentials — one motor per side — are banned) while still letting the rear wheels rotate at different speeds in corners.

---

## 5. Design Iterations

The drivetrain went through two revisions before it worked. Both are visible in the current parts.

### Iteration 1 — Eliminating differential axial play

**Problem.** The differential sat between the two carrier rings with a small axial gap, so it could slide sideways ("wiggle") between them. A stable gear mesh needs the differential held at a fixed axial position.

**Solutions considered and rejected.**
- *Thicken the left carrier ring inward* — rejected: the motor's bevel pinion occupies that space.
- *Thicken the right carrier ring inward* — rejected: it would collide with the gear on that side.

**Chosen solution.** A separate thin retaining ring (`differantial_holder`, 2.25 mm) glued with cyanoacrylate to the right carrier ring. It surrounds the differential's bearing and fills the gap without intruding into the space either gear needs.

**Result.** No axial play, full gear clearance on both sides. The packaging constraint blocked both obvious fixes and forced a third one.

### Iteration 2 — Stabilizing the rear wheels

**Problem.** Originally each 4 mm drive shaft was supported only at its inboard end, at the differential carrier. The wheel hung on the free end of a cantilever — any play at the single support was amplified at the wheel, and the rear wheels visibly tilted and wobbled.

**Solution.** An outboard bearing block per side (`left_shaft_holder`, `right_shaft_holder`), each holding a bearing that carries the shaft next to the wheel. Every rear shaft is now supported at two points.

**Result.** The wheels run true. Load is shared between the carrier rings and the shaft holders instead of the rings bending alone.

---

## 6. Parts List

| # | Part | Qty | Bounding box (mm) | Function |
|---|---|-----|---|---|
| 1 | `main_base.stl` | 1 | 254.0 × 100.0 × 55.0 | Chassis plate. Integrated JGB37-520 motor mount, mounting points for every subassembly, columns for the upper decks. |
| 2 | `front_top.stl` | 1 | 90.1 × 115.0 × 25.5 | Front deck: holds the MG996R servo and the camera mast. |
| 3 | `middle_top.stl` | 1 | 100.0 × 75.0 × 16.9 | Middle deck: carries the main soldered PCB. |
| 4 | `back_top.stl` | 1 | 100.0 × 68.0 × 22.0 | Rear deck: carries the Raspberry Pi 5 and power bank. |
| 5 | `camera_holder.stl` | 1 | 40.0 × 24.1 × 154.7 | Camera mast; holds the Camera Module 3 at height, angled at the track. |
| 6 | `ackerman_rod.stl` | 1 | 76.9 × 8.0 × 8.0 | Steering tie rod linking both knuckles, driven at its center by the servo arm. |
| 7 | `left_knuckle.stl` | 1 | 17.1 × 47.8 × 12.0 | Left steering knuckle: kingpin pivot, wheel axle, tie-rod eye. |
| 8 | `right_knuckle.stl` | 1 | 17.1 × 47.8 × 12.0 | Right steering knuckle, exact mirror of the left. |
| 9 | `servo_arm.stl` | 1 | 33.5 × 12.0 × 7.5 | Custom arm on the servo's splined output, linking to the tie-rod center. |
| 10 | `differantial_gear.stl` | 1 | 14.5 × 15.9 × 14.5 | Bevel pinion on the motor shaft; drives the differential crown gear. |
| 11 | `left_differantial_ring.stl` | 1 | 21.9 × 40.0 × 17.0 | Left differential carrier: bearing seat, bolts to chassis. |
| 12 | `right_differantial_ring.stl` | 1 | 21.9 × 40.0 × 17.0 | Right differential carrier, mirror of the left. |
| 13 | `differantial_holder.stl` | 1 | 2.2 × 16.6 × 16.6 | Retaining ring eliminating differential axial play (Iteration 1). |
| 14 | `differantial_cup.stl` | 1 | 28.2 × 13.2 × 13.2 | Drive cup coupling differential output to the rear shaft. |
| 15 | `left_shaft_holder.stl` | 1 | 4.0 × 28.0 × 13.0 | Left outboard bearing block for the 4 mm drive shaft (Iteration 2). |
| 16 | `right_shaft_holder.stl` | 1 | 4.0 × 28.0 × 13.0 | Right outboard bearing block, mirror of the left. |

Total printed volume (solid): ≈ 170 cm³.

---

## 7. Technical Drawings

Dimensioned multi-view drawings for every part, exported from Fusion 360, in [`drawings/`](drawings/):

| Drawing | Covers |
|---|---|
| [`main_base.pdf`](drawings/main_base.pdf) | Chassis plate |
| [`front_top.pdf`](drawings/front_top.pdf) | Front deck |
| [`mid_top.pdf`](drawings/mid_top.pdf) | Middle deck |
| [`back_top.pdf`](drawings/back_top.pdf) | Rear deck |
| [`camera_holder.pdf`](drawings/camera_holder.pdf) | Camera mast |
| [`ackerman_rod.pdf`](drawings/ackerman_rod.pdf) | Steering tie rod |
| [`knuckles.pdf`](drawings/knuckles.pdf) | Left & right knuckles |
| [`servo_arm.pdf`](drawings/servo_arm.pdf) | Servo arm |
| [`motor_gear.pdf`](drawings/motor_gear.pdf) | Bevel pinion |
| [`differantial_cup.pdf`](drawings/differantial_cup.pdf) | Drive cup |
| [`differantial_rings&holder.pdf`](drawings/differantial_rings%26holder.pdf) | Carrier rings & retaining ring |
| [`shaft_holder.pdf`](drawings/shaft_holder.pdf) | Outboard bearing blocks |

---

## 8. Vehicle Regulation Compliance

| Rule | Requirement | Our design |
|---|---|---|
| 11.1 | Footprint ≤ 300 × 200 mm, height ≤ 300 mm | Chassis 254 × 100 mm; tallest point (camera mast on chassis) well under the height limit |
| 11.2 | Weight ≤ 1.5 kg | All printed parts ≈ 170 cm³ solid volume — roughly 100–130 g at typical infill, leaving ample margin for electronics and battery |
| 11.3 | One driving axle, one steering actuator | Single rear axle driven by one JGB37-520; single MG996R steering servo |
| 11.5 | No electronic differential | Mechanical (WLTOYS 144001) differential — one motor, gears split the torque |

*Final assembled dimensions and weight will be added after the vehicle is complete.*

---

## 9. Printing Notes

Parts were printed across several different printers (printing was distributed among team helpers), which imposed a design constraint of its own: hole and slot fits carry clearance so parts remain assemblable despite printer-to-printer tolerance differences.

*Per-part material and settings summary: pending. Editable source files (.f3d / .step) will be added to a `source/` folder.*

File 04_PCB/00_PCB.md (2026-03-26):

# PCB
Custom PCB design, schematics, and fabrication outputs.

## Contents
| Path | Description |
|---|---|

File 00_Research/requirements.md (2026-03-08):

# Requirements 

## Table of Contents

## Car
#### - Physical Requirements
    - Dimensions: Max 300mm (L) × 200mm (W) × 300mm (H).
    - Weight: Max 1.5 kg.
    - Wheels: 4 wheels (no omnidirectional, ball casters, or spherical wheels).
    - Must have one driving axle
    - Steering actuator (servo motor)

#### - Autonomy & Electronics
    - Autonomous Only (No remote control, Wi-Fi, Bluetooth, or external signals during runs.)
    - **Sensors**: Any type allowed (e.g., cameras, ultrasonic, IMU, line sensors).
    - **Motors**:
        - Max 2 driving motors (must be mechanically linked to wheels via gears/axles).
        - Additional motors allowed for steering (servos)

#### - Power & Safety
    - **Batteries**: Any type allowed (no fuel cells).
    - **Switches**: **One power button** to turn on the vehicle, **One start button** (separate from power) to begin the program.
    -
 
#### - Controllers
    - one Raspberry Pi + one Arduino, or two ESP32s
    - If two, communications wireless between them is perhebitied
    
#### - Prohibited Designs
    - Differential drives (e.g., two motors controlling left/right wheels independently).
    - Omnidirectional wheels (e.g., mecanum).
    - Pre-built commercial robot kits unless significantly modified.

## Plagiarism
#### - Copied Code
    - Using code from online sources (e.g., GitHub, tutorials) without significant modification.
    - Using unmodified commercial robot kits (e.g., ready-made self-driving car platforms).
    - Modular kits (e.g., LEGO Mindstorms) are allowed only if the team designs unique mechanics/code.
    - First GITHUB commit must contain ≥20% of the final code.

## Required Sensors & motors
    - Infrared Line Sensors
    - Raspberry Pi Camera Module v3 (Wide-Angle)
    - TOF
    
    - TT Gear Motor (compatible with motor drivers, built-in encoder for speed feedback.) or Pololu 37D Metal Gearmotor
    - Servo Motor

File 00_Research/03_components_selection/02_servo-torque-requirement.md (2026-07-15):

# Steering Servo Torque Requirement

This document calculates the minimum torque a steering servo must provide to turn the front wheels of the vehicle under realistic competition conditions. No specific component is named — this defines the requirement the selected servo must meet.

---

## Table of Contents

- [1. The Steering Load Problem](#1-the-steering-load-problem)
- [2. Vehicle Parameters](#2-vehicle-parameters)
- [3. Calculating Steering Torque](#3-calculating-steering-torque)
  - [3.1 Normal Force on Front Axle](#31-normal-force-on-front-axle)
  - [3.2 Tire Scrub Torque](#32-tire-scrub-torque)
  - [3.3 Kingpin Moment Arm](#33-kingpin-moment-arm)
  - [3.4 Total Steering Torque Required](#34-total-steering-torque-required)
- [4. Safety Factor](#4-safety-factor)
- [5. Speed Requirement](#5-speed-requirement)
- [6. Summary of Requirements](#6-summary-of-requirements)
- [Sources](#sources)

---

## 1. The Steering Load Problem

The servo must overcome two resistive forces to turn the front wheels:

1. **Tire scrub torque** — friction between the tire contact patch and the floor as the wheel pivots about the kingpin axis
2. **Inertial load** — resistance of the front wheel assembly mass to angular acceleration

Of these two, tire scrub torque dominates at low speed on a hard floor. Inertial load is negligible at the steering speeds involved and is not calculated separately.

The worst case is **static steering** — turning the wheels while the robot is stationary. Once the robot is moving, rolling reduces the effective friction and steering becomes easier.

---

## 2. Vehicle Parameters

| Parameter | Value | Notes |
|---|---|---|
| Total robot mass `m` | 0.7 kg | Target build weight |
| Front axle load fraction | 40% | Rear-drive vehicle, rear-heavy |
| Front axle normal force `N_f` | 0.7 × 0.40 × 9.81 = **2.75 N** | Weight on front wheels |
| Tire contact patch radius `r_cp` | ~15 mm | Estimated from wheel width |
| Coefficient of friction `μ` | 0.6 | Rubber on competition mat |
| Kingpin moment arm `d` | ~8 mm | Distance from kingpin axis to tie rod pivot |
| Wheelbase `L` | 90 mm | Front to rear axle |
| Track width `T` | 140 mm | Center to center of front wheels |

> **Front axle load fraction:** A rear-wheel-drive vehicle with battery and motor mounted rearward carries approximately 40% of its weight on the front axle. This is a conservative estimate — less front load means less steering torque required. Using 40% ensures the requirement is not underestimated.

---

## 3. Calculating Steering Torque

### 3.1 Normal Force on Front Axle

The total normal force pressing the front wheels against the floor:

```
N_f = m × g × front_fraction
N_f = 0.7 × 9.81 × 0.40
N_f = 2.75 N
```

This is split equally between two front wheels, so each wheel carries:

```
N_per_wheel = 2.75 / 2 = 1.375 N
```

### 3.2 Tire Scrub Torque

When a wheel pivots about its kingpin axis, the contact patch resists rotation. The scrub torque per wheel is modeled as a distributed friction force acting over the contact patch:

```
τ_scrub_per_wheel = μ × N_per_wheel × r_cp
τ_scrub_per_wheel = 0.6 × 1.375 × 0.015
τ_scrub_per_wheel = 0.01238 N·m = 1.238 kg·cm
```

Total scrub torque for both front wheels:

```
τ_scrub_total = 2 × 1.238 = 2.475 kg·cm
```

### 3.3 Kingpin Moment Arm

The servo does not push directly on the kingpin — it acts through a steering arm (tie rod linkage). The mechanical advantage of this linkage determines how much servo torque translates to wheel rotation torque.

For a steering arm length of `d = 8 mm` at the wheel, and assuming a 1:1 servo horn to tie rod geometry:

```
τ_servo_required = τ_scrub_total × (r_cp / d)
τ_servo_required = 2.475 × (15 / 8)
τ_servo_required = 2.475 × 1.875
τ_servo_required ≈ 4.64 kg·cm
```

> **Note:** This ratio depends on the actual steering arm geometry. A longer steering arm reduces the required servo torque. An 8 mm arm is a conservative (short) estimate based on the chassis scale at 90 mm wheelbase.

### 3.4 Total Steering Torque Required

```
τ_required = 4.64 kg·cm
```

---

## 4. Safety Factor

The calculation above uses idealized assumptions:

- Perfectly flat floor with uniform friction
- No binding in the kingpin bearings
- No inertial spike at direction reversal
- No flex in the tie rod or servo horn

A **2× safety factor** is applied to account for these real-world conditions:

```
τ_servo_minimum = τ_required × 2
τ_servo_minimum = 4.64 × 2 ≈ 9.3 kg·cm
```

**The servo stall torque must exceed 9.3 kg·cm at the operating voltage.**

> Standard hobby servos are rated at either 4.8V or 6.0V. The torque at 6.0V is typically 20–30% higher than at 4.8V. The requirement of ≥ 9.3 kg·cm must be met at the actual supply voltage used.

---

## 5. Speed Requirement

The servo must complete a full steering sweep within the time available during a corner approach. The robot approaches a corner at cruise speed and must redirect the wheels before entering the turn.

**Available time for steering sweep:**

At cruise speed of 0.8 m/s, and with the ToF sensor detecting a corner opening at ~150 mm ahead:

```
t_available = distance / speed = 0.150 / 0.8 = 0.19 s
```

**Required angular speed:**

The servo must sweep from center to maximum lock in under 0.19 seconds. Assuming maximum lock is approximately 30°:

```
ω_required = 30° / 0.19 s ≈ 158 °/s
```

Converting to the standard hobby servo speed unit (seconds per 60°):

```
speed_required = 60° / 158°/s ≈ 0.38 s/60°
```

**The servo must achieve full 60° sweep in under 0.38 seconds at operating voltage.**

> Most standard hobby servos achieve 0.10–0.25 s/60° at 6V, comfortably within this requirement. Speed is not the limiting constraint — torque is.

---

## 6. Summary of Requirements

| Requirement | Minimum Value | Notes |
|---|---|---|
| Stall torque | **≥ 9.3 kg·cm** | At operating voltage, with 2× safety factor |
| Speed | **≤ 0.38 s/60°** | At operating voltage |
| Operating voltage | 5V–6V | Must be isolated from logic rail to prevent stall transients resetting MCU |
| Form factor | Standard servo (38×20×30 mm) | Must fit within 300×200 mm chassis |
| Control interface | PWM (50 Hz, 500–2500 µs pulse) | Standard hobby servo protocol |

---

## Sources

| Source | Description |
|---|---|
| Milliken & Milliken — Race Car Vehicle Dynamics (SAE, 1995) | Steering torque and scrub moment theory |
| Norton, R.L. — Machine Design | Linkage mechanical advantage, moment arm calculations |
| [WRO 2026 Future Engineers Rules](https://wro-association.org) | Vehicle dimensions, single steering actuator requirement |
| [FIRGELLI Automations — Ackermann Steering Linkage](https://www.firgelliauto.com/blogs/mechanisms/ackermann-steering-linkage) | Steering arm geometry reference |

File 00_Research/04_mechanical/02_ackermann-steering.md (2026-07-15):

# Ackermann Steering Geometry

This document covers the engineering basis for the steering system used in the WRO 2026 Future Engineers vehicle. It explains what Ackermann geometry is from first principles, how it compares to alternative steering configurations, the math behind it, and why it was selected for this robot.

---

## Table of Contents

- [1. The Steering Problem](#1-the-steering-problem)
- [2. What Is Ackermann Geometry](#2-what-is-ackermann-geometry)
- [3. How It Works Mechanically](#3-how-it-works-mechanically)
- [4. The Ackermann Condition — Math](#4-the-ackermann-condition--math)
- [5. Steering Geometry Types](#5-steering-geometry-types)
  - [5.1 Parallel Steering (0% Ackermann)](#51-parallel-steering-0-ackermann)
  - [5.2 Pure Ackermann (100%)](#52-pure-ackermann-100)
  - [5.3 Anti-Ackermann (Reverse)](#53-anti-ackermann-reverse)
- [6. What We Use](#6-what-we-use)
- [7. Effect on Robot Navigation](#7-effect-on-robot-navigation)
- [8. Turning Radius Calculation](#8-turning-radius-calculation)
- [Sources](#sources)

---

## 1. The Steering Problem

When a vehicle turns, each wheel traces a different arc. The inner wheel follows a tight radius while the outer wheel follows a wider one. Both wheels must cover their respective arcs **in the same time** — which means they must travel at different speeds, or equivalently, point at different angles.

<figure style="text-align: center;">
  Wheel arc difference in a turn
  <figcaption>Fig 1.1 — In a turn, the inner wheel traces a shorter arc than the outer wheel</figcaption>
</figure>

If both front wheels are forced to point at the same angle (parallel steering), one of them must **scrub** — drag sideways across the floor. On a competition mat, this introduces:

- Lateral displacement that is unpredictable in software
- Reduced odometry accuracy
- Increased positioning error for parking maneuvers

> **The core problem Ackermann solves:** How do you mechanically ensure the inner wheel always turns more sharply than the outer wheel, for every steering angle, without software control?

---

## 2. What Is Ackermann Geometry

<figure style="text-align: center;">
  Ackermann steering animation
  <figcaption>Fig 2.1 — Ackermann geometry in action: inner wheel turns more than outer wheel</figcaption>
</figure>

<br>

Ackermann steering geometry is a **purely mechanical** solution. It was invented by German carriage builder Georg Lankensperger in Munich in 1816, and patented in England by his agent Rudolph Ackermann in 1818 — originally for horse-drawn carriages.

The principle: arrange the steering linkage so that lines drawn through each front wheel's steering axis converge at a single point on the rear axle. This causes the inner wheel to automatically rotate through a larger angle than the outer wheel during any turn, keeping both wheels pointed toward a common turn center with no scrub.

<figure style="text-align: center;">
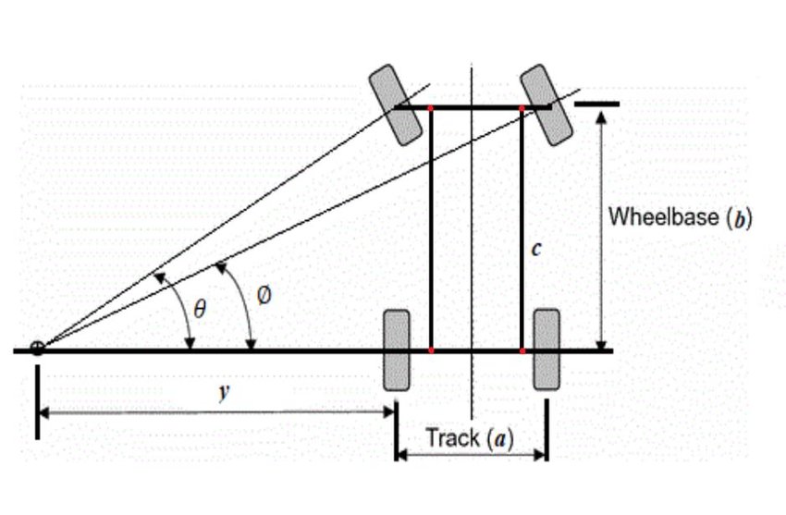
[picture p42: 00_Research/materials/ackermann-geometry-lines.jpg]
Ackermann geometry construction lines
  
  <figcaption>Fig 2.2 — Lines through each kingpin and steering arm must meet at the center of the rear axle for perfect Ackermann</figcaption>
</figure>

> **Key property:** Ackermann geometry is purely kinematic — it is not affected by external forces. The correct wheel angles are achieved through linkage geometry alone, requiring no sensors, no software, and no active control.

---

## 3. How It Works Mechanically

The steering linkage consists of four key elements:

| Component | Function |
|---|---|
| **Kingpins** | Vertical pivot points at each front wheel hub |
| **Steering arms** | Levers attached to each kingpin, angled inward |
| **Tie rod** | Rigid bar connecting both steering arms |
| **Servo / rack** | Input that pushes or pulls the tie rod sideways |

<figure style="text-align: center;">
  Ackermann trapezoid linkage
  <figcaption>Fig 3.1 — The steering arms and tie rod form a trapezoid shape when wheels are straight ahead</figcaption>
</figure>

**The inward angle of the steering arms is the key.** When the tie rod is pushed left:

1. The left steering arm rotates, pulling the left wheel to a sharp angle (inner wheel)
2. The right steering arm rotates, pushing the right wheel to a shallower angle (outer wheel)
3. Because the arms are angled inward, this differential is built into the geometry

**Straight ahead:** Both wheels point forward in parallel. No differential needed.

**In a turn:** The trapezoidal geometry automatically generates the correct difference in angle between the inner and outer wheels, for any steering input magnitude.

<figure style="text-align: center;">
  Ackermann steering turning animation
  <figcaption>Fig 3.2 — As the servo turns the steering, the inner wheel always rotates through a larger angle than the outer</figcaption>
</figure>

---

## 4. The Ackermann Condition — Math

For perfect Ackermann geometry, the following trigonometric relationship must hold at every steering angle:

```
cot(δ_outer) - cot(δ_inner) = T / L
```

| Variable | Meaning |
|---|---|
| `δ_outer` | Angle of the outer (less-turned) front wheel |
| `δ_inner` | Angle of the inner (more-turned) front wheel |
| `T` | Track width — distance between the two front wheel centerlines |
| `L` | Wheelbase — distance between front and rear axles |

This is called the **Ackermann condition**. When it is satisfied, all four wheels trace concentric circles around a single turn center, with zero lateral scrub.

### Applying to this robot

Our chassis parameters:

| Parameter | Value |
|---|---|
| Wheelbase `L` | ~180 mm |
| Track width `T` | ~120 mm |

At a moderate inner steering angle of `δ_inner = 30°`:

```
cot(δ_outer) = cot(30°) - T/L
cot(δ_outer) = 1.732 - (120/180)
cot(δ_outer) = 1.732 - 0.667 = 1.065
δ_outer = arccot(1.065) ≈ 43.2° → δ_outer ≈ 23.2°
```

So the outer wheel should turn approximately **23°** while the inner wheel turns **30°**. The Ackermann trapezoid linkage achieves this automatically through geometry.

### Turning Radius

The overall turning radius (measured from the rear axle center) is:

```
R = L / tan(δ_avg)
```

Where `δ_avg` is approximately the average of the two front wheel angles. At `δ_avg ≈ 26.5°`:

```
R = 180 / tan(26.5°) ≈ 180 / 0.499 ≈ 360 mm
```

The robot can complete a **~360 mm radius turn** at moderate steering lock. The WRO track corners have an inner wall radius large enough to accommodate this.

---

## 5. Steering Geometry Types

Three fundamentally different geometries exist. The choice affects positional accuracy, tire wear, and — critically for competition — the consistency of turns.

### 5.1 Parallel Steering (0% Ackermann)

Both front wheels turn through the same angle regardless of which is inner or outer.

<figure style="text-align: center;">
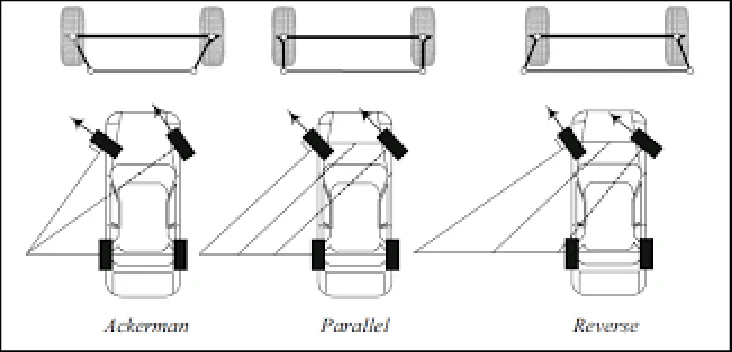
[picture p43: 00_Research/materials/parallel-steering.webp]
Parallel steering diagram
  
  <figcaption>Fig 5.1 — Parallel steering: both wheels at same angle, causing inner wheel scrub</figcaption>
</figure>

| Property | Value |
|---|---|
| Scrub | High — inner wheel drags sideways |
| Mechanical simplicity | High — simpler linkage |
| Positional accuracy | Low — lateral displacement from scrub |
| Turn consistency | Poor — scrub force varies with speed and floor friction |

**Why rejected:** Scrub-induced lateral displacement is not constant. It varies with floor friction, speed, and tire compound — making it impossible to compensate reliably in software. In the obstacle challenge, this directly compromises parking precision.

### 5.2 Pure Ackermann (100%)

Inner wheel turns more than outer wheel, satisfying the Ackermann condition exactly.

<figure style="text-align: center;">
  Pure Ackermann diagram
  <figcaption>Fig 5.2 — Pure Ackermann: all four wheels point to a common turn center</figcaption>
</figure>

| Property | Value |
|---|---|
| Scrub | Minimal to zero at low speed |
| Mechanical simplicity | Moderate — trapezoidal linkage |
| Positional accuracy | High |
| Turn consistency | High — predictable arc |

**Why selected:** Ideal for low-speed, precision maneuvering. The WRO competition operates entirely in the low-speed regime where Ackermann geometry is most effective.

### 5.3 Anti-Ackermann (Reverse)

Outer wheel turns more than inner wheel — the reverse of Ackermann.

| Property | Value |
|---|---|
| Scrub | Very high at low speed |
| Use case | High-speed racing only — improves slip angle balance at speed |
| Positional accuracy | Low |

**Why rejected:** Anti-Ackermann is designed for high-speed motorsport where tyre slip angles dominate. At robot competition speeds (< 1 m/s), it produces worse scrub than even parallel steering.

### Comparison Table

| Geometry | Scrub at Low Speed | Turn Consistency | Parking Precision | Use Case |
|---|---|---|---|---|
| Parallel (0%) | High | Poor | Low | Simple mechanisms, off-road |
| Ackermann (100%) | Zero | High | High | Road vehicles, robots, forklifts |
| Anti-Ackermann | Very High | Very Poor | Very Low | High-speed racing only |

---

## 6. What We Use

The robot uses a **pure Ackermann front steering geometry** actuated by an MG996R servo motor.

**Reasons for selection:**

- **Zero scrub:** Eliminates unpredictable lateral displacement during turns. Directly improves heading accuracy and parking repeatability.
- **Software simplicity:** Because the geometry is correct mechanically, the IMU-based heading controller does not need to compensate for scrub. The robot turns where it is pointed.
- **Competition relevance:** The WRO track consists of 90° corners at low speed. This is exactly the operating regime where Ackermann geometry outperforms alternatives.
- **Rule compliance:** WRO 2026 requires a single steering actuator. A servo driving a standard Ackermann trapezoid linkage is the most direct implementation.
- **Precedent:** Consistently used by top-placing WRO Future Engineers teams including LazyGo (Bangladesh, 2025) and Nerdvana (Romania, 2024).

**Implementation:**

The MG996R servo output horn connects to the tie rod. The steering arms on each front kingpin are angled inward to form the Ackermann trapezoid. The servo pulse width is mapped to steering angle via the `set_angle()` API in `servo_control.c`.

---

## 7. Effect on Robot Navigation

Ackermann geometry has direct consequences for the software architecture:

**Heading hold (straight lines):** With zero scrub, the robot's actual heading closely tracks the IMU heading. The forward PID controller corrects only genuine drift (e.g., from floor unevenness), not scrub-induced displacement.

**90° turns:** The turn controller commands a fixed heading change via the IMU. Because the wheels track geometrically correct arcs, the robot reaches the target heading predictably without needing to compensate for lateral error introduced by scrub.

**Odometry:** The encoder on the rear axle reads the true distance traveled. Without scrub, encoder-derived distance maps directly to forward displacement. This is used for lap counting and finish-section positioning.

> **Contrast with a solid axle:** On a solid axle robot, every 90° turn introduces scrub-derived lateral displacement of several centimeters. This displacement is not captured by the encoder and not corrected by the IMU heading controller, causing cumulative positional error across 3 laps × 4 corners = 12 turns.

---

## 8. Turning Radius Calculation

The minimum turning radius constrains whether the robot can fit through the WRO track corners without hitting the inner wall.

**Track corner geometry (from WRO 2026 rules):**
- Inner wall forms the inner boundary of the corner section
- The robot must stay within the corridor (600–1000 mm wide depending on the round)

**Robot turning radius at full servo lock:**

```
R_min = L / tan(δ_max)
```

With our chassis (`L ≈ 180 mm`) and servo maximum angle (`δ_max ≈ 30°`):

```
R_min = 180 / tan(30°) = 180 / 0.577 ≈ 312 mm
```

The minimum turning radius is approximately **312 mm**, measured from the rear axle to the turn center. This is comfortably within the WRO corner geometry, which allows for a much larger radius. The robot is not turning radius-limited on this track.

---

## Sources

| Source | Description |
|---|---|
| [Wikipedia — Ackermann Steering Geometry](https://en.wikipedia.org/wiki/Ackermann_steering_geometry) | Geometry definition, history, Lankensperger patent |
| [Tire Technology International — The Story of Ackermann Steering](https://www.tiretechnologyinternational.com/opinion/the-story-of-ackermann-steering.html) | History, dynamic vs. kinematic Ackermann, industry usage |
| [FIRGELLI Automations — Ackermann Steering Linkage Mechanism](https://www.firgelliauto.com/blogs/mechanisms/ackermann-steering-linkage) | Interactive diagram, trapezoidal linkage explanation |
| [Suspension Secrets — Ackermann](https://suspensionsecrets.co.uk/ackermann/) | Slip angle theory, motorsport applications |
| [Flow Racers — Ackermann Steering Geometry](https://flowracers.com/blog/ackermann-steering-geometry/) | Practical explanation of Ackermann percentage |
| [ResearchGate — Design and Development of Four-Wheel Steering for ATV](https://www.researchgate.net/figure/Ackermann-steering-mechanism-This-is-the-diagram-for-the-Ackermann-steering-mechanism_fig1_346561431) | Scientific diagram of Ackermann mechanism with labeled parameters |
| [LazyGo WRO 2025 — Bangladesh](https://github.com/A-N-M-Noor/LazyGo_WRO2025) | Reference team Ackermann implementation |
| [Nerdvana WRO 2024 — Romania](https://github.com/mihaipriboi/WRO_Future_Engineers_2024) | Reference team Ackermann implementation |
| Milliken & Milliken — Race Car Vehicle Dynamics (SAE, 1995) | Ackermann condition derivation, steering geometry theory |
| [WRO 2026 Future Engineers Rules](https://wro-association.org) | Track dimensions, single steering actuator requirement |

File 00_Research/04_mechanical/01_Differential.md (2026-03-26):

# Differential Drive System

This document covers the engineering basis for the differential drivetrain used in the WRO 2026 Future Engineers vehicle. It explains what a differential is from first principles, the different types available, why we selected an open bevel gear differential, and how it compares to a solid axle approach.

---

## Table of Contents

- [1. What Is a Differential](#1-what-is-a-differential)
- [2. How It Works Mechanically](#2-how-it-works-mechanically)
- [3. Types of Differentials](#3-types-of-differentials)
    - [3.1 Open Differential](#31-open-differential)
    - [3.2 Limited-Slip Differential (LSD)](#32-limited-slip-differential-lsd)
    - [3.3 Locking Differential](#33-locking-differential)
    - [3.4 Torsen (Torque-Sensing) Differential](#34-torsen-torque-sensing-differential)
    - [3.5 Electronic Differential](#35-electronic-differential)
- [4. What We Use](#4-what-we-use)
- [5. Differential vs Solid Axle](#5-differential-vs-solid-axle)
- [6. Effect on Torque Calculations](#6-effect-on-torque-calculations)
- [Sources](#sources)

---

## 1. What Is a Differential

A **differential** is a mechanical assembly that takes a single rotating input shaft and splits its rotation into two output shafts — the two driven wheels — while allowing each output shaft to spin at a **different speed**.

<figure id="fig-3-1" style="text-align: center;"> 
 <figcaption>Fig 3.1 - Moving differential</figcaption> </figure>

This is necessary because in any turn, the outer wheel must travel a longer arc than the inner wheel. If both wheels are forced to rotate at the same speed, one of them must scrub (slide) sideways across the floor to compensate. On a competition surface, this introduces lateral forces that fight the steering and reduce positional precision.

The differential solves this purely through mechanical geometry — no software, no sensors, no active control. The speed difference between the two wheels happens automatically in response to the resistance each wheel encounters.

As you can see in [Fig 3.1](#fig-3-1), when the car moves toward the right, the left (green) shaft starts to move faster.

---

## 2. How It Works Mechanically

The core of a bevel gear differential consists of:

- A **ring gear** (or differential housing), driven by the motor
- Two **side gears**, one per output shaft (one per wheel)
- Two or four **spider gears** (also called planet gears), sitting between the side gears inside the housing

**Straight line:** The spider gears do not rotate on their own axes. Both side gears turn at the same speed as the housing — both wheels spin identically.

**In a turn:** The outer wheel encounters less resistance than the inner wheel (which is being slowed by the tighter arc). This resistance imbalance causes the spider gears to rotate on their own axes, transferring speed from the slower inner wheel to the faster outer wheel. The average speed of the two wheels always equals the input speed from the motor.

> **Key property:** The differential preserves the **average** speed of the two wheels equal to the input shaft speed. It does not change the total torque — it splits it equally between both wheels (minus friction losses).

---

## 3. Types of Differentials

### 3.1 Open Differential

The standard bevel gear differential described above. Torque is split equally between both wheels at all times.

**Characteristics:**

- Simplest and lightest design
- No active components
- If one wheel loses traction completely, all torque goes to that wheel and the other receives none (the weakness of open differentials in off-road use)
- On a flat, consistent competition floor this weakness is irrelevant

**Used in:** Standard RC cars.

### 3.2 Limited-Slip Differential (LSD)

Adds clutch packs or friction cones between the spider gears and the housing. When speed difference between the two wheels exceeds a threshold, the clutch engages and partially locks the differential, sending more torque to the slower wheel.

**Characteristics:**

- Better traction on uneven or slippery surfaces
- Mechanically more complex and heavier
- Unnecessary for a flat competition floor

### 3.3 Locking Differential

A manually or electronically actuated mechanism that rigidly locks both side gears together, forcing both wheels to spin at exactly the same speed.

**Characteristics:**

- Maximum traction in off-road conditions
- Causes severe wheel scrub on hard surfaces when locked
- Functionally equivalent to a solid axle when engaged

### 3.4 Torsen (Torque-Sensing) Differential

Uses worm gears instead of bevel gears. The worm gear geometry is inherently self-locking in one direction, which means torque is biased toward the wheel with more grip automatically and continuously.

**Characteristics:**

- More responsive than clutch-based LSDs
- Higher manufacturing precision required
- Significantly more complex to fabricate at small scale

### 3.5 Electronic Differential

No mechanical differential at all. Two separate motors, one per wheel, with a control system that calculates the required speed difference based on steering angle and IMU data, then applies it via PWM.

**Characteristics:**

- Requires two drive motors — **not compliant with WRO 2026 rules** which require a single driving axle with motors mechanically linked
- Eliminates mechanical complexity but adds software complexity
- Used in some robotic platforms but ruled out for this competition

---

## 4. What We Use

The drivetrain uses a **standard open bevel gear differential**, the simplest configuration that satisfies the WRO single driving axle requirement while eliminating wheel scrub in turns.

**Reasons for selection:**

- **Rule compliance:** A single motor driving both wheels through a mechanical linkage fully satisfies the WRO 2026 single driving axle requirement.
- **Sufficient for competition surface:** The WRO arena is a flat, consistent floor. The open differential's traction limitation under wheel spin is not a relevant failure mode here.
- **Lowest complexity:** No clutch packs, no active locking, no electronics required in the drivetrain itself.
- **Weight and size:** Open differentials at RC car scale are compact and light, fitting comfortably within the 300 × 200 mm chassis constraint.

**Gear ratio through the differential:** 1:1. The differential does not change the overall gear ratio — torque multiplication happens upstream in the motor's internal gearbox, not in the differential.

---

## 5. Differential vs Solid Axle

A **solid axle** (also called a locked axle) rigidly connects both wheels to the same shaft. Both wheels are forced to spin at identical speeds at all times.

|Property|Open Differential|Solid Axle|
|---|---|---|
|Turning behaviour|Clean — wheels rotate at natural arc speeds|Wheel scrub — one or both wheels slide sideways|
|Positional accuracy|High|Lower — scrub introduces lateral displacement error|
|Mechanical complexity|Moderate|Simple|
|Torque losses|~5–10% (gear mesh friction)|Minimal|
|Odometry accuracy|Good — encoder reads average of both wheels|Good on straights, error accumulates in turns|
|Parallel parking precision|High|Reduced due to turn scrub|
|Weight|Slightly heavier|Lighter|
|Used by top WRO teams|Yes — consistently at international level|Occasionally at national level|

**Why wheel scrub matters for this competition specifically:**

The obstacle challenge requires the robot to pass traffic sign pillars on a specific side and then execute a precise parallel park. Wheel scrub during turns introduces lateral displacement that is difficult to compensate for in software because it is not consistent — it varies with speed, floor friction, and tire compound. A differential eliminates this variable entirely.

<figure id="fig-3-1" style="text-align: center;"> 
 <figcaption>Fig 3.2 - Wheels turning distances</figcaption> </figure>

> **Note:** Several teams that placed well in the open challenge with a solid axle struggled with parking precision in the obstacle challenge. The lateral displacement from wheel scrub under turns is the primary cause.

---

## 6. Effect on Torque Calculations

Two separate effects must be distinguished:

**Friction losses (efficiency):** The differential's gear mesh and bearing friction consumes some torque before it reaches the wheels. This is already accounted for in the drivetrain efficiency factor (η = 0.70) used in 01-motor-selection-criteria, which explicitly lists differential gears as one of the loss sources.

**Gear ratio:** A standard bevel gear differential is always 1:1. It does not multiply or reduce torque. Torque at the two output shafts equals torque at the input shaft minus friction losses — split equally between both wheels.

Increasing or decreasing the physical size of the differential's internal bevel gears does not change the 1:1 ratio. Size only marginally affects the friction losses. To achieve gear reduction, a separate gear stage must be placed before or after the differential — not inside it.

**Net effect on motor selection:** The differential adds no torque multiplication and does not change the minimum stall torque requirement of ≥ 3.5 kg·cm calculated in 01-motor-selection-criteria.

---

## Sources

| Source | Description |
| --- | --- |
| [LazyGo WRO 2025 — Bangladesh](https://github.com/A-N-M-Noor/LazyGo_WRO2025) | Reference team differential implementation and justification |
| [Nerdvana Cancer WRO 2024 — Romania](https://github.com/mihaipriboi/WRO_Future_Engineers_2024) | Reference team differential implementation |
| [WRO Future Engineers Getting Started Guide](https://world-robot-olympiad-association.github.io/future-engineers-gs/p01-chassis/) | Official guidance on chassis and drivetrain approaches |
| [WRO 2026 Future Engineers Rules](https://wro-association.org) | Single driving axle requirement, vehicle size constraints |
| Shigley's Mechanical Engineering Design | Differential gear theory, torque splitting, efficiency |
| Norton, R.L. — Machine Design | Bevel gear geometry and power transmission |
| [Differential \| How does it work? - By saiban](https://youtu.be/nC6fsNXdcMQ?si=Ch_aLKpvTPvUU6L_) | Useful YouTube video explaining how differential actually works |

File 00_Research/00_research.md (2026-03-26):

# Research

This directory is the pre-implementation research workspace.
It contains everything before any build decisions are finalized.

---

## Contents

| Path | Description |
| --- | --- |
| [`01_rules/`](./01_rules/00_rules.md) | Official WRO 2026 rules, summaries, and reading notes |
| [`02_wro-references/`](./02_wro-references/00_wro-references.md) | External links, helpful resources, and other teams' repos |
| [`requirements.md`](./requirements.md) | Derived system requirements from rules and constraints |
| [`track.png`](./track.png) | Official track layout reference image |

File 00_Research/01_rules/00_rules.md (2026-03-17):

# Rules

Contains all materials related to the official WRO 2026

---

## Contents

| File | Description |
|---|---|
| [`01_WRO-2026-Future-Engineers-Se....pdf`](./01_WRO-2026-Future-Engineers-Se....pdf) | Official unmodified rules document from WRO |
| [`02_rules-summary.pdf`](./02_rules-summary.pdf) | Condensed summary of key rules |
| [`03_rules-notes.md`](./03_rules-notes.md) | Personal notes, highlights, and flagged ambiguities |

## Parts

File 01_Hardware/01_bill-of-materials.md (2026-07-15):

# Bill of Materials (BOM)

Final component list for the WRO 2026 Future Engineers vehicle. Each entry links to the research document that justifies the requirement it meets.

---

## Table of Contents

- [1. Compute](#1-compute)
- [2. Sensors](#2-sensors)
- [3. Actuators](#3-actuators)
- [4. Motor Driver](#4-motor-driver)
- [5. Power](#5-power)
- [6. Full Table](#6-full-table)

---

## 1. Compute

<p align="center">
  Raspberry Pi 5
  ESP32 DevKitC 32D
</p>

| Component | Role |
|---|---|
| **Raspberry Pi 5** | High-level logic, camera and vision processing |
| **ESP32-DEVKITC-32D** | Low-level control: sensors, motor, servo, FreeRTOS tasks |

Split chosen to separate real-time control (ESP32) from vision workloads (Pi 5), avoiding jitter in motor/servo timing caused by heavier vision processing.

---

## 2. Sensors

<p align="center">
  BNO055 IMU
  VL53L0X ToF
</p>

| Component | Qty | Role |
|---|---|---|
| **BNO055** | 1 | Absolute heading (yaw) for turn control and heading hold |
| **VL53L0X** | 3 | Front, left, right distance — corner and wall detection |

See [`01_motor-selection-criteria.md`](../00_Research/03_components_selection/01_motor-selection-criteria.md) for related speed/timing requirements that drove sensor update-rate needs.

---

## 3. Actuators

<p align="center">
  JGB37-520 DC motor
  MG996R servo
</p>

| Component | Role | Requirement met |
|---|---|---|
| **JGB37-520** (12V DC gear motor) | Rear drive | Stall torque ≥ 3.5 kg·cm — see [`01_motor-selection-criteria.md`](../00_Research/03_components_selection/01_motor-selection-criteria.md) |
| **MG996R** servo | Front Ackermann steering | Stall torque ≥ 9.3 kg·cm — see [`02_servo-torque-requirement.md`](../00_Research/03_components_selection/02_servo-torque-requirement.md) |

---

## 4. Motor Driver

<p align="center">
  TB6612FNG driver
</p>

| Component | Role |
|---|---|
| **TB6612FNG** | Single-channel H-bridge for the drive motor |

Single motor uses one channel; the second channel on the chip is unused.

---

## 5. Power

<p align="center">
  3S Li-Ion battery
  MP1584EN buck converter
</p>

| Component | Qty | Role |
|---|---|---|
| **3S Li-Ion battery** | 1 | Main power source |
| **MP1584EN buck converter** | 2 | One 5V rail (logic), one 6V rail (servo, isolated) |
| **Hall-effect encoder** | 1 | Wheel speed / distance feedback, mounted on motor shaft |

Dual regulator design isolates the servo from the logic rail so servo stall current spikes cannot brown out the ESP32. See [`03_passive-components.md`](../00_Research/03_components_selection/03_passive-components.md) for capacitor sizing on each rail.

---

## 6. Full Table

| # | Component | Qty | Category | Interface |
|---|---|---|---|---|
| 1 | Raspberry Pi 5 | 1 | Compute | — |
| 2 | ESP32-DEVKITC-32D | 1 | Compute | UART to Pi 5 |
| 3 | BNO055 | 1 | Sensor | I2C |
| 4 | VL53L0X | 3 | Sensor | I2C (address-switched via XSHUT) |
| 5 | Hall-effect encoder | 1 | Sensor | Digital GPIO (ISR) |
| 6 | JGB37-520 DC gear motor | 1 | Actuator | PWM via TB6612FNG |
| 7 | MG996R servo | 1 | Actuator | PWM (LEDC) |
| 8 | TB6612FNG | 1 | Driver | GPIO + PWM |
| 9 | 3S Li-Ion battery | 1 | Power | — |
| 10 | MP1584EN buck converter | 2 | Power | 5V logic rail, 6V servo rail |

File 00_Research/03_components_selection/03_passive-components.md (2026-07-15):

# Passive Components — Capacitors and Resistors

This document calculates the requirements for decoupling capacitors, bulk capacitors, and pull resistors used across the circuit. These are theoretical requirements based on standard design practice, not a list of parts used.

---

## Table of Contents

- [1. Decoupling Capacitors](#1-decoupling-capacitors)
- [2. Bulk Capacitors](#2-bulk-capacitors)
- [3. Pull-Down Resistors](#3-pull-down-resistors)
- [4. Pull-Up Resistors](#4-pull-up-resistors)
- [5. Summary](#5-summary)
- [Sources](#sources)

---

## 1. Decoupling Capacitors

<p align="center">
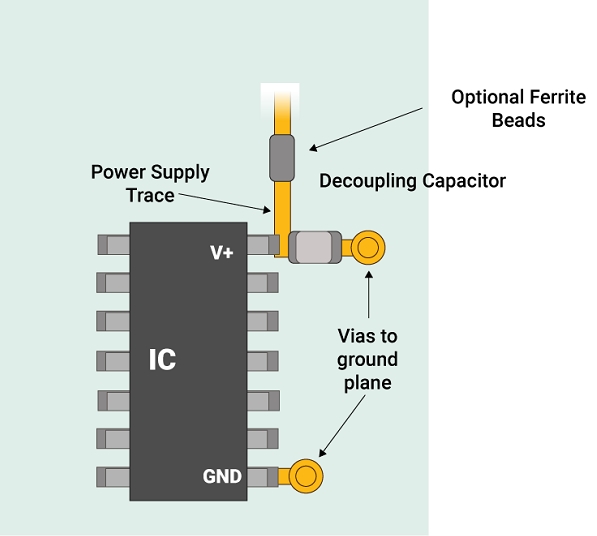
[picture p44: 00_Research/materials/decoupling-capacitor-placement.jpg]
decoupling capacitor placement
  
</p>

A decoupling capacitor sits right next to an IC's power pin. It supplies a quick burst of current when the chip switches state, so the chip doesn't pull that current from the long, slow power trace.

**Why it's needed:** Every digital switch (a GPIO toggling, a motor driver switching) causes a short current spike. Wires and traces have inductance, so they resist sudden current changes. Without a local capacitor, this causes voltage dips that can reset or glitch nearby ICs.

**Calculation — required capacitance:**

```
C = I × Δt / ΔV
```

| Variable | Meaning |
|---|---|
| `I` | Transient current spike |
| `Δt` | Duration of the switching event |
| `ΔV` | Maximum acceptable voltage dip |

Example, for a digital IC drawing a 50 mA transient spike over 10 ns, with a 0.1V allowed dip:

```
C = (0.05 × 10×10⁻⁹) / 0.1
C = 5 nF
```

**Standard practice value:** 100 nF (0.1 µF) ceramic capacitor per IC power pin. This value is oversized relative to the calculation above on purpose — it's cheap, small, and covers a wide range of switching speeds without needing per-chip calculation.

**Placement rule:** Within 2–5 mm of the IC's VCC pin, directly between VCC and GND.

---

## 2. Bulk Capacitors

<p align="center">
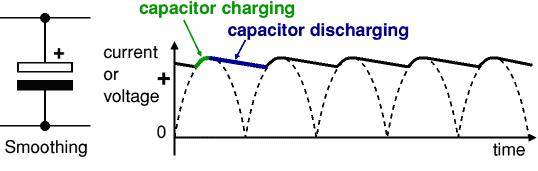
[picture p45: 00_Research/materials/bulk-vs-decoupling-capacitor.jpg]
bulk vs decoupling capacitor
  
</p>

A bulk capacitor is larger and sits near the power input of a board or rail. It smooths out slower, larger current demands — like a motor starting or a servo moving under load — that a small decoupling cap cannot supply fast enough.

**Why it's needed:** Decoupling caps handle nanosecond-scale spikes. Motor stall current and servo current draw happen on a millisecond scale and pull much more current. Without a bulk cap, the whole rail voltage sags when the motor starts.

**Calculation — required capacitance:**

```
C = I × Δt / ΔV
```

Example, for a motor drawing a 2A stall current spike over 5 ms, with a 0.3V allowed sag:

```
C = (2 × 5×10⁻³) / 0.3
C = 33.3 mF ≈ 33,000 µF
```

This is unrealistically large for a single capacitor — in practice this load is handled by a combination of:
- The battery's own low internal resistance
- A moderate bulk cap (100–470 µF) at the regulator output
- The regulator's own transient response

**Standard practice value:** 100–470 µF electrolytic capacitor at each regulator output, in addition to the small decoupling caps at each IC.

---

## 3. Pull-Down Resistors

<p align="center">
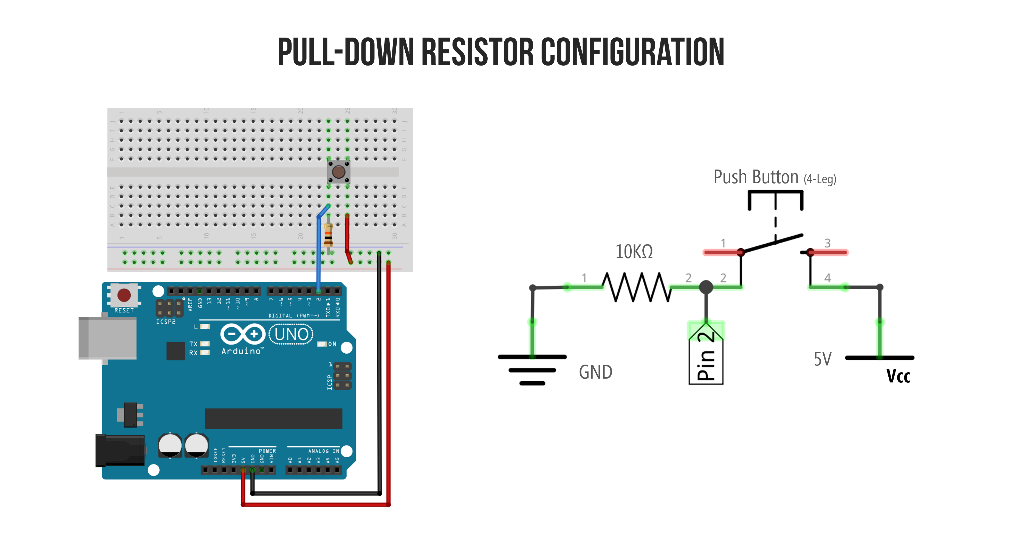
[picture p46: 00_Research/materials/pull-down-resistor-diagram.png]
pull down resistor diagram
  
</p>

A pull-down resistor connects a signal pin to ground through a resistor. When nothing is actively driving the pin, it settles at a known LOW state instead of floating.

**Why it's needed:** A floating digital input can read as random HIGH or LOW due to electrical noise. On a control pin like a motor driver's IN1/IN2/STBY, this is dangerous — the motor could spin unexpectedly on power-up before the microcontroller initializes.

**Calculation — required resistance:**

The resistor value is a trade-off:
- **Too low** → wastes current when the pin is actively driven HIGH
- **Too high** → too slow to pull down, more sensitive to noise

```
I_leak = V / R
```

For a 5V logic level and a target leakage current under 1 mA:

```
R ≥ V / I_leak
R ≥ 5 / 0.001
R ≥ 5 kΩ
```

**Standard practice value:** 10 kΩ. This is high enough to draw negligible current when the pin is driven, and low enough to firmly hold LOW when undriven.

**Where this applies:** Any control input pin that must default to a known safe state before the microcontroller boots and takes over — for example, motor driver direction and enable pins.

---

## 4. Pull-Up Resistors

<p align="center">
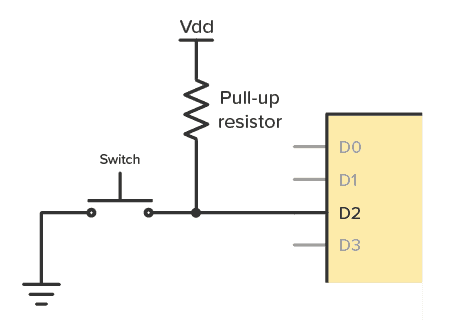
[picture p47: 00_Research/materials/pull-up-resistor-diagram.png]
pull up resistor diagram
  
</p>

A pull-up resistor is the mirror of a pull-down: it connects a signal pin to the supply voltage through a resistor, so the pin defaults HIGH instead of LOW when nothing drives it.

**Why it exists:** Some devices communicate using open-drain outputs (I2C is the most common example) — they can only pull a line LOW, never drive it HIGH. A pull-up resistor is required to bring the line back to HIGH when released.

**Calculation — same formula as pull-down:**

```
R ≥ V / I_leak
```

For 5V logic and 1 mA leakage limit:

```
R ≥ 5 kΩ
```

**Standard practice value:** 4.7 kΩ–10 kΩ, same reasoning as the pull-down case.

**Why not used in this design:** All control signals in this circuit (motor driver inputs, servo PWM) are actively push-pull driven by the microcontroller at all times after boot — they are never left floating or open-drain. I2C buses (ToF sensors, IMU) already have internal or module-level pull-ups on their SDA/SCL lines, so no additional pull-ups were required on the main board.

---

## 5. Summary

| Component | Value | Purpose |
|---|---|---|
| Decoupling capacitor | 100 nF ceramic | Per-IC high-frequency noise suppression |
| Bulk capacitor | 100–470 µF electrolytic | Rail-level current surge smoothing |
| Pull-down resistor | 10 kΩ | Safe default LOW on control pins before MCU boot |
| Pull-up resistor | 4.7–10 kΩ (not used) | Would be needed only for open-drain signals |

---

## Sources

| Source | Description |
|---|---|
| [Sierra Circuits — Decoupling Capacitor Placement Guidelines](https://www.protoexpress.com/) | Placement and value selection practice |
| Horowitz & Hill — The Art of Electronics | Decoupling and bulk capacitor theory |
| [Aticleworld — Pull-Up Resistor: How It Works](https://aticleworld.com/) | Pull-up resistor calculation and use cases |
| TI Application Report — Understanding and Using Decoupling Capacitors | Transient current and voltage dip calculation basis |

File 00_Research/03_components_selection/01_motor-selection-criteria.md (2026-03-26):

# Drive Motor Selection

This document covers the engineering process for selecting a drive motor
for the WRO 2026 Future Engineers vehicle. It explains the underlying
physics, the calculations used.

---

## Table of Contents

- [1. Setup and Drivetrain Configuration](#1-setup-and-drivetrain-configuration)
- [2. Understanding Torque](#2-understanding-torque)
- [3. Calculating Required Torque](#3-calculating-required-torque)
- [4. Calculating Required Speed](#4-calculating-required-speed)
- [5. The Speed-Torque Curve](#5-the-speed-torque-curve)
---

## 1. Setup and Drivetrain Configuration

The vehicle uses a **single rear drive motor** connected to both rear wheels
through a differential. The differential allows the two wheels to rotate at
different speeds during turns, which is necessary for Ackermann steering
geometry to work correctly.

```
Battery → Motor → Differential → Rear Left Wheel
                              → Rear Right Wheel
```

<p align="center">
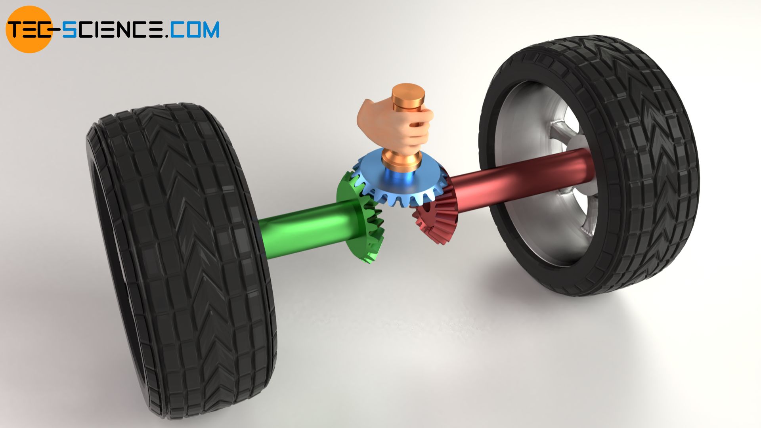
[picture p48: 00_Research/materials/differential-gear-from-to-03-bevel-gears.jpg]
  

</p>

Because there is only one motor, its full torque output passes through a
single shaft into the differential. There is no per-wheel torque splitting
at the motor stage.

> **Rule compliance:** WRO 2026 Future Engineers rules prohibit one motor
> per wheel. A single motor driving both wheels through a mechanical
> linkage (differential) is fully compliant.

---

## 2. Understanding Torque

Torque is a rotational force — specifically, **force applied at a distance
from a pivot point.**

A practical way to think about it: pushing a door near the hinge requires
much more force than pushing at the far edge. The force is the same, but the
distance from the hinge (the moment arm) changes how effective it is.
That product of force × distance is torque.

For a drive wheel:

```
τ = F × r
```

| Variable | Meaning |
|---|---|
| `τ` | Torque (N·m or kg·cm) |
| `F` | Force applied at the wheel contact patch (N) |
| `r` | Wheel radius — the moment arm (m) |

Rearranged to find force at the ground:

```
F = τ / r
```

A motor with higher torque, or a smaller wheel radius, produces more pushing
force at the ground.

### Unit Conversion

Most hobby motor datasheets use `kg·cm`. To convert to SI:

```
1 kg·cm = 0.0981 N·m
```

---

## 3. Calculating Required Torque

The motor must provide enough torque to cover two conditions simultaneously:
accelerating the robot from rest, and overcoming rolling resistance during
motion.

### 3.1 Robot Parameters
All of which are arbitrary choosen, where I think that is the max we need for each.

| Parameter | Value |
|---|---|
| Robot mass `m` | 1.2 kg |
| Target acceleration `a` | 1.5 m/s² |
| Wheel radius `r` | 0.0325 m | 
|Rolling resistance coefficient `μ` | 0.05 |

### 3.2 Force Required at the Ground

**Acceleration force** — the force needed to change the robot's velocity:

```
F_accel = m × a
F_accel = 1.2 × 1.5 = 1.8 N
```

**Rolling resistance force** — friction between wheel and floor at constant motion:

```
F_roll = μ × m × g
F_roll = 0.05 × 1.2 × 9.81 = 0.59 N
```

**Total force required at the ground:**

```
F_total = F_accel + F_roll
F_total = 1.8 + 0.59 = 2.39 N
```

### 3.3 Required Torque at the Wheel

```
τ_wheel = F_total × r
τ_wheel = 2.39 × 0.0325 = 0.0777 N·m ≈ 0.79 kg·cm
```

### 3.4 Account for Drivetrain Losses

Torque is lost at every mechanical junction — the motor gearbox, differential
gears, and axle bearings. A realistic combined drivetrain efficiency is
**~70%**, meaning 30% of torque is consumed before reaching the ground.

> The differential is a standard 1:1 bevel gear type, introducing no gear ratio transformation. All drivetrain losses are captured by the efficiency factor η = 0.70."

```
τ_required = τ_wheel / η
τ_required = 0.79 / 0.70 ≈ 1.13 kg·cm
```

### 3.5 Apply the Safety Factor

The calculation above assumes ideal conditions — a perfectly flat clean floor,
no chassis flex, no variation in bearing friction, and no static friction
spike at startup. In practice, static friction at startup is always higher
than rolling friction, and conditions vary between rounds.

The standard rule for mobile robot motor sizing is to select a motor whose
**stall torque is at least 3× the calculated operating requirement.** This
simultaneously covers real-world losses and ensures the motor operates at
30–40% of its stall torque during normal driving. 

```
τ_stall_minimum = 1.13 × 3 = 3.4 kg·cm
```

**The motor stall torque must exceed ~3.5 kg·cm.**

---

## 4. Calculating Required Speed

### 4.1 Target Linear Speed

The WRO track is approximately **3 meters per lap**, making 3 laps roughly
9 meters of total driving distance.

The round time limit is 3 minutes, but time must be reserved for:
- Obstacle detection and avoidance reactions
- Deceleration before tight turns
- The parallel parking maneuver
- Stopping correctly in the finish section

Targeting driving completion in **~70 seconds** gives comfortable margin:

```
Minimum average speed = 9 m / 70 s ≈ 0.13 m/s
```

A practical cruise target is **0.5–1.0 m/s**, allowing the vehicle to slow
for obstacles and still finish well within the time limit.

### 4.2 Convert Speed to Required RPM

At a cruise target of **0.8 m/s**:

```
RPM = (v × 60) / (2π × r)
RPM = (0.8 × 60) / (2π × 0.0325)
RPM ≈ 235 RPM
```

The motor output shaft needs to spin at approximately **235 RPM** at cruise.
A motor rated above this provides headroom that is controlled via PWM
duty cycle.

---

## 5. The Speed-Torque Curve

A DC motor cannot simultaneously produce maximum torque and maximum speed.
The relationship between the two is **linear**, defined by two fixed endpoints:

<p align="center">
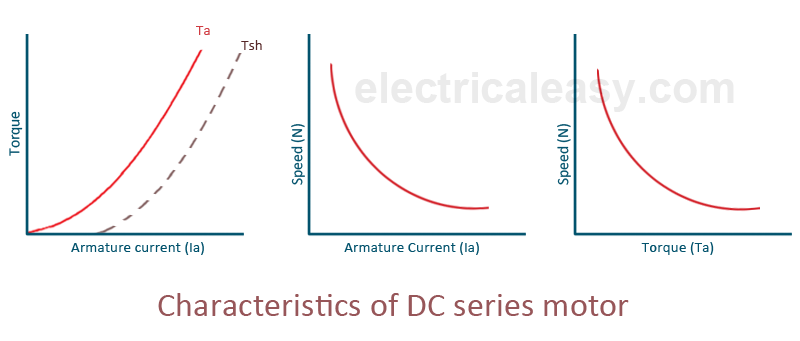
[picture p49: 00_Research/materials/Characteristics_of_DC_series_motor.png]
  
</p>

| Operating Point | Speed | Torque | Current Draw |
|---|---|---|---|
| No-load | Maximum | ~0 | Minimum |
| Target zone | Mid-range | 30–50% of stall | Moderate |
| Stall | 0 RPM | Maximum | Maximum |

### Why operating near stall is dangerous

- Current draw is at maximum → motor and driver overheat
- Gearbox is under peak stress → accelerated wear or mechanical failure
- Efficiency is near zero → all electrical input becomes heat, not motion

### The operating zone rule

The motor should be selected such that the expected operating torque falls
between 30–50% of its stall torque:

```
τ_stall ≥ τ_operating / 0.40
τ_stall ≥ 1.13 / 0.40 ≈ 2.83 kg·cm
```

This result converges with the 3× safety factor from Section 3.5. Both
methods confirm the stall torque must be above **~3.0–3.5 kg·cm.**

---

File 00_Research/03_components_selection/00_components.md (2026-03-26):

# Components

Hardware component research for the robot build.

---

## Contents

| File | Description |
| --- | --- |
| [`01_motor-selection.md`](./01_motor-selection.md) | The criteria to choose the drive motor |

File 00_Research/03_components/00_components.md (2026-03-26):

# Components

Hardware component research for the robot build.

---

## Contents

| File | Description |
| --- | --- |
| [`01_motor-selection.md`](./01_motor-selection.md) | The criteria to choose the drive motor |
| [`02_Differential`](./02_Differential.md) | What is a **differential** and why we choose it, which models specifically were selected |

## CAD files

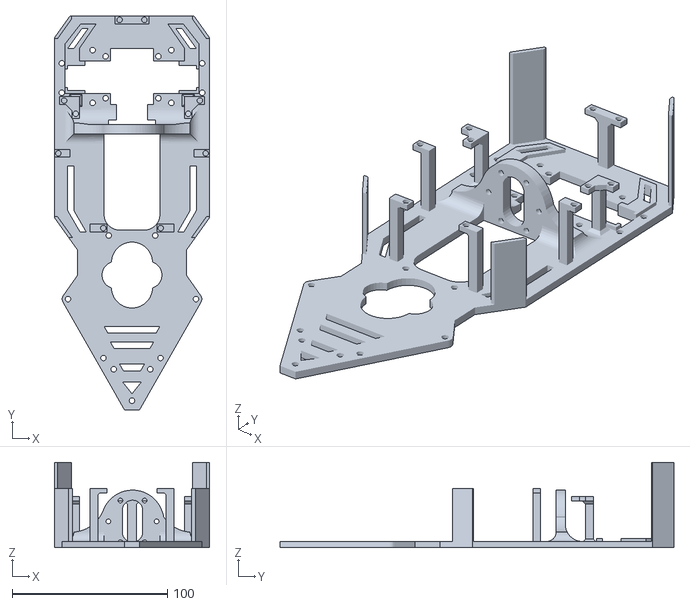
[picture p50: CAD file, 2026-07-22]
03_Models/stl/main_base.stl
100.0 x 254.0 x 55.0

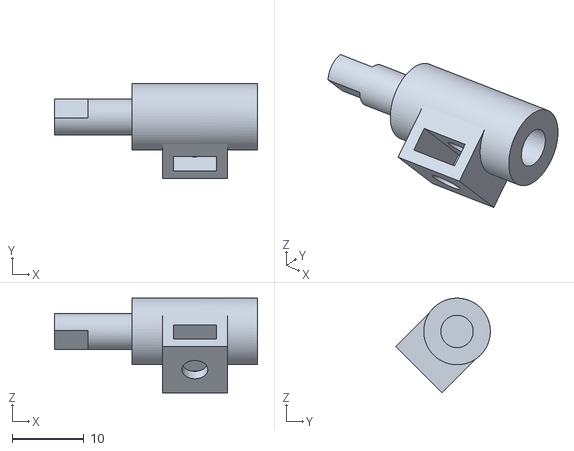
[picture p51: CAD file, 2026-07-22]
03_Models/stl/differantial_cup.stl
28.2 x 13.2 x 13.2

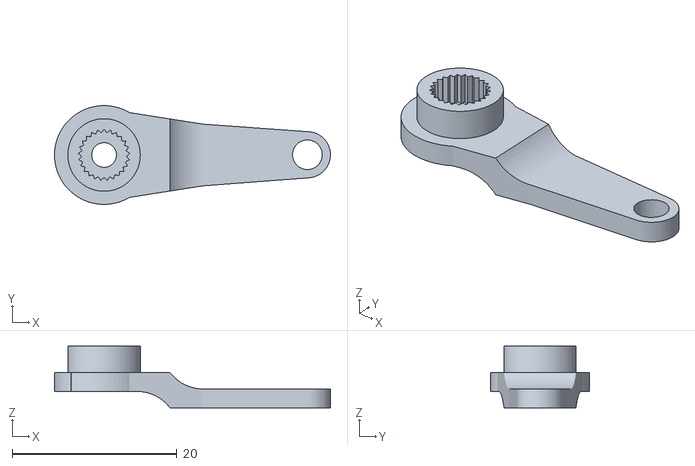
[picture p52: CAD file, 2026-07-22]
03_Models/stl/servo_arm.stl
33.5 x 12.0 x 7.50

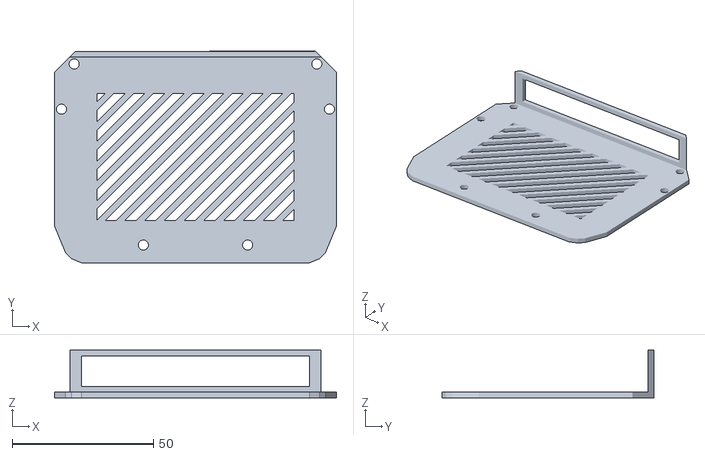
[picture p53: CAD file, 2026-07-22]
03_Models/stl/middle_top.stl
100.0 x 75.0 x 16.9

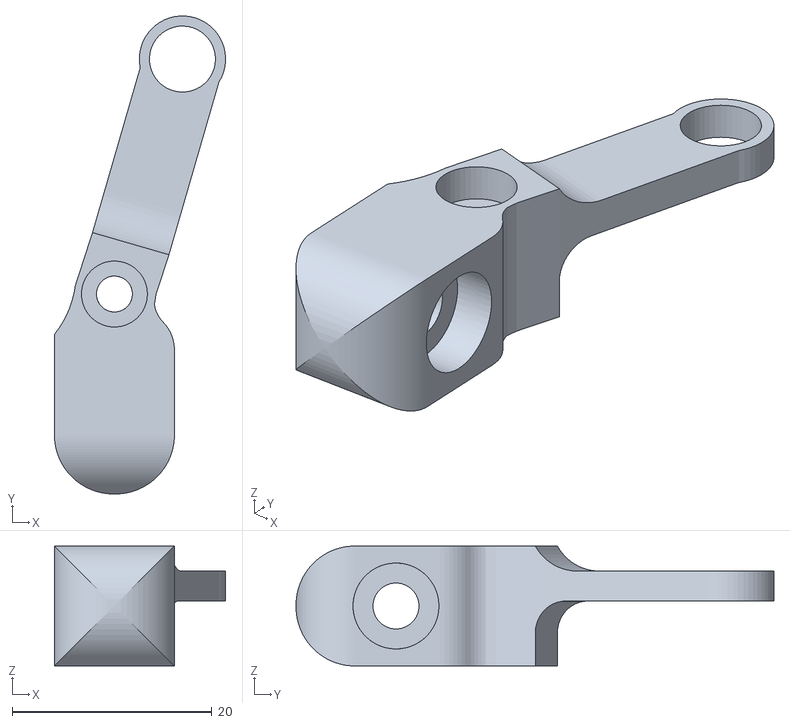
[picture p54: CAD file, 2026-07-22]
03_Models/stl/right_knuckle.stl
17.1 x 47.8 x 12.0

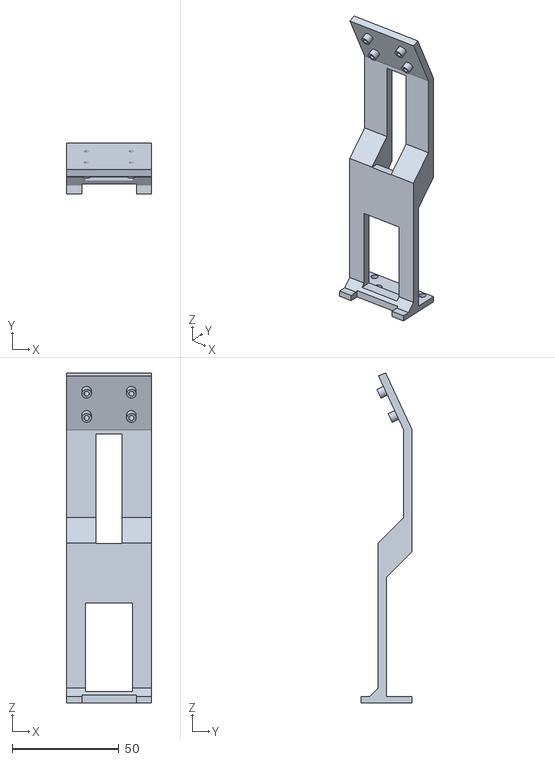
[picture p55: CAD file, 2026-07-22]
03_Models/stl/camera_holder.stl
40.0 x 24.1 x 154.7

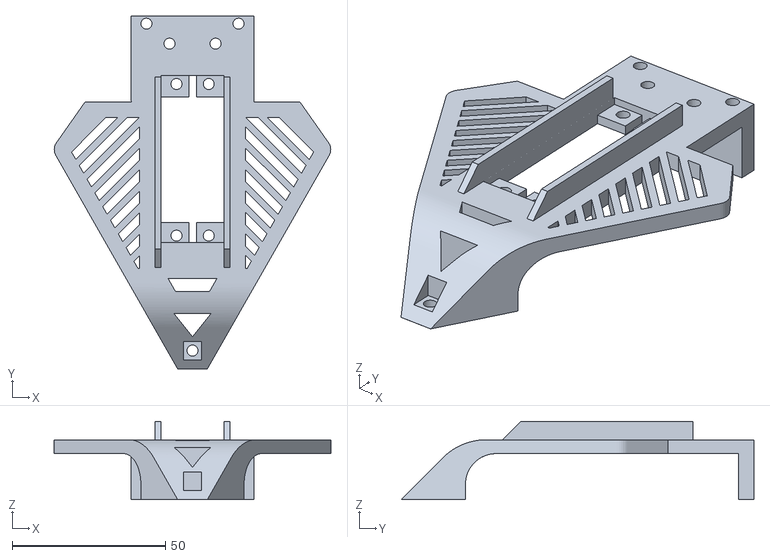
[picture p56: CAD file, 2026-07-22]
03_Models/stl/front_top.stl
90.1 x 115.0 x 25.5

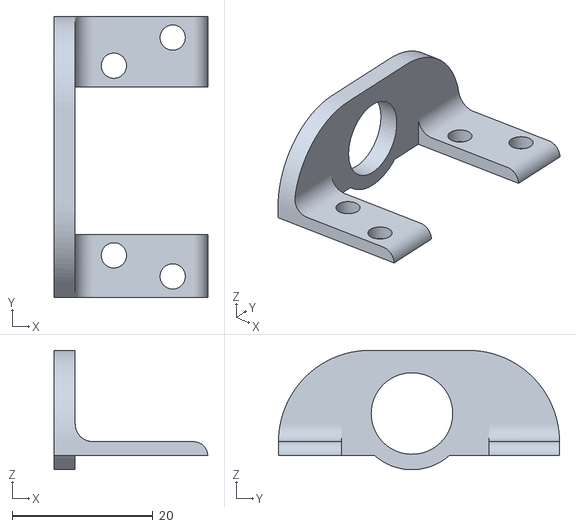
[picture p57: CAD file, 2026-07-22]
03_Models/stl/left_differantial_ring.stl
21.9 x 40.0 x 17.0

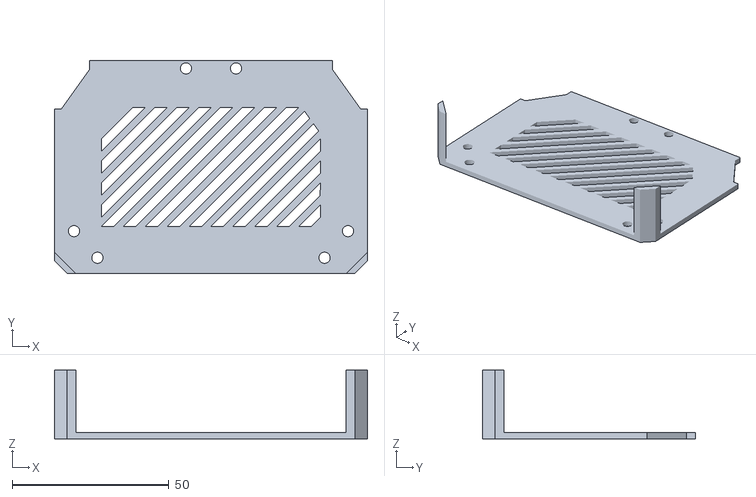
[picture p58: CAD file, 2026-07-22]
03_Models/stl/back_top.stl
100.0 x 68.0 x 22.0

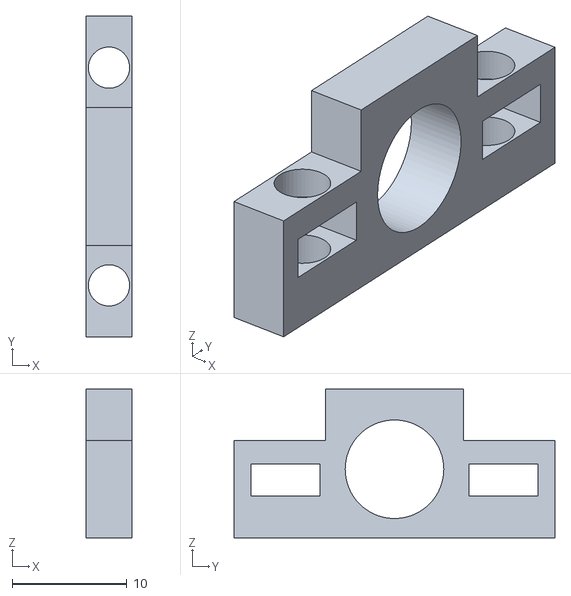
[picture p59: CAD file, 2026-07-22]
03_Models/stl/left_shaft_holder.stl
4.00 x 28.0 x 13.0

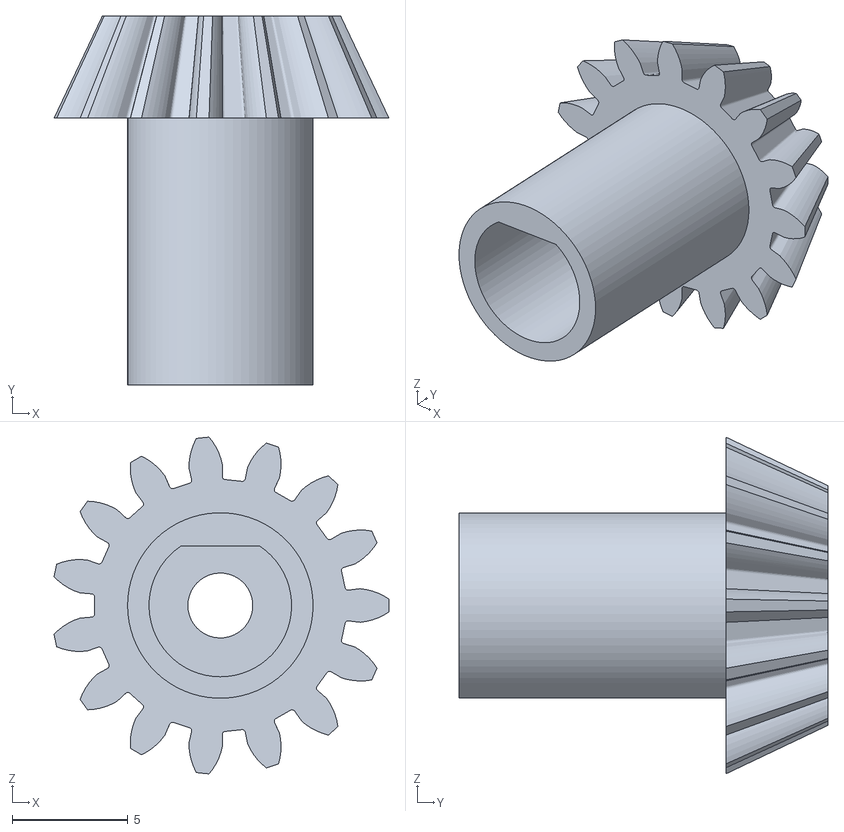
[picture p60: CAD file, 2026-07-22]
03_Models/stl/differantial_gear.stl
14.5 x 15.9 x 14.5

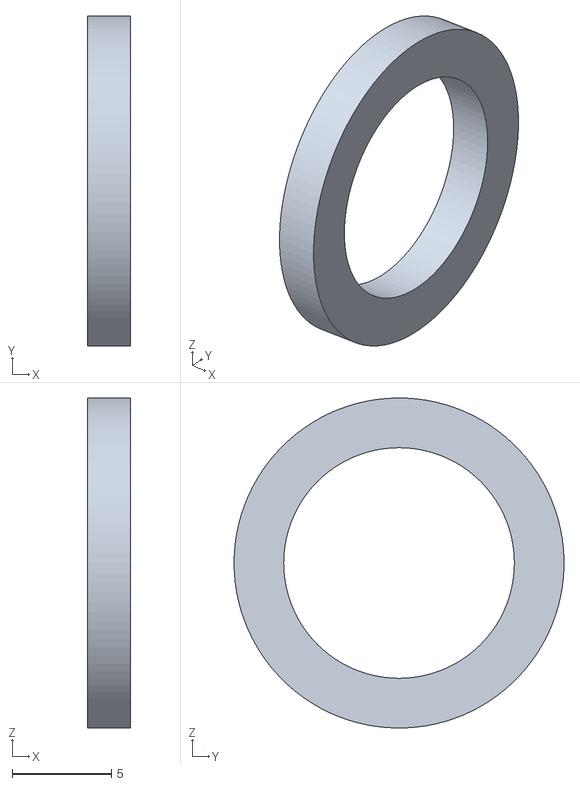
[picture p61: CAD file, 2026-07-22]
03_Models/stl/differantial_holder.stl
2.15 x 16.6 x 16.6

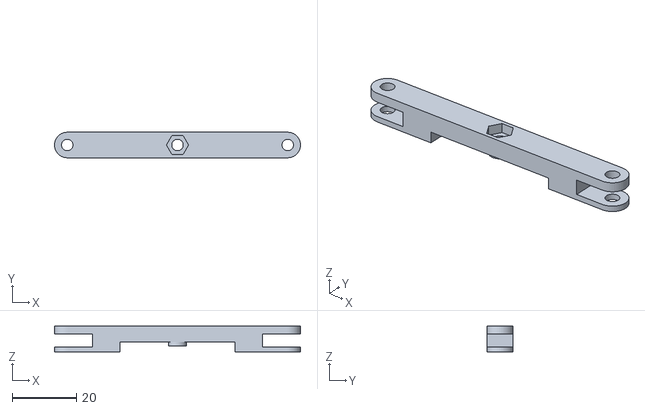
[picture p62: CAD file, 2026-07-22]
03_Models/stl/ackerman_rod.stl
76.9 x 8.00 x 8.00

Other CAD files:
03_Models/stl/right_differantial_ring.stl
03_Models/stl/left_knuckle.stl
03_Models/stl/right_shaft_holder.stl

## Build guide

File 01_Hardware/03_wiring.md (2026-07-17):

# Wiring

---

## Table of Contents

- [1. I2C Buses](#1-i2c-buses)
- [2. Motor Driver (TB6612FNG)](#2-motor-driver-tb6612fng)
- [3. Servo](#3-servo)
- [4. Encoder](#4-encoder)
- [5. ToF XSHUT Pins](#5-tof-xshut-pins)
- [6. Pi 5 ↔ ESP32 UART](#6-pi-5--esp32-uart)
- [7. Full Pinout Table](#7-full-pinout-table)

---

## 1. I2C Buses

Two separate I2C buses isolate the ToF sensors (which require XSHUT address remapping) from the IMU.

| Bus | Port | SDA | SCL | Frequency | Devices |
|---|---|---|---|---|---|
| IMU bus | I2C_NUM_1 | GPIO22 | GPIO23 | 400 kHz | BNO055 |
| ToF bus | I2C_NUM_0 | GPIO27 | GPIO14 | 400 kHz | 3× VL53L0X |

---

## 2. Motor Driver (TB6612FNG)

| Signal | GPIO |
|---|---|
| IN1 | GPIO18 |
| IN2 | GPIO5 |
| PWM | GPIO17 |
| STBY | GPIO19 |

LEDC assignment: Timer 0, Channel 0, 20 kHz, 10-bit resolution.

---

## 3. Servo

| Signal | GPIO |
|---|---|
| PWM (signal) | GPIO32 |

LEDC assignment: Timer 1, Channel 1, 50 Hz, 16-bit resolution. Pulse width range 500–2500 µs (MID = 1500 µs, requires physical calibration).

---

## 4. Encoder

| Signal | GPIO |
|---|---|
| Signal (hall-effect) | GPIO21 |

Single hall-effect sensor, interrupt-driven (`IRAM_ATTR` ISR), `volatile` tick counter.

---

## 5. ToF XSHUT Pins

| Sensor | XSHUT GPIO | I2C Address (after remap) |
|---|---|---|
| Right | GPIO26 | 0x30 |
| Front | GPIO13 | 0x32 |
| Left | GPIO25 | 0x31 |

All three sensors boot at the default address 0x29. XSHUT sequencing powers them up one at a time so each can be individually reassigned to a unique address before the next is enabled.

---

## 6. Pi 5 ↔ ESP32 UART

| Signal | Pi 5 GPIO | ESP32 |
|---|---|---|
| TX → RX | GPIO14 | RX pin |
| RX ← TX | GPIO15 | TX pin |

Pi 5 side uses `/dev/ttyAMA0`. Not yet implemented in firmware — reserved pins only at this stage.

---

## 7. Full Pinout Table

| Function | GPIO | Notes |
|---|---|---|
| IMU SDA | 22 | I2C_NUM_1 |
| IMU SCL | 23 | I2C_NUM_1 |
| ToF SDA | 27 | I2C_NUM_0 |
| ToF SCL | 14 | I2C_NUM_0 |
| Motor IN1 | 18 | TB6612FNG |
| Motor IN2 | 5 | TB6612FNG |
| Motor PWM | 17 | TB6612FNG, LEDC Timer 0 Ch 0 |
| Motor STBY | 19 | TB6612FNG |
| Servo PWM | 32 | LEDC Timer 1 Ch 1 |
| Encoder | 21 | Hall-effect ISR |
| ToF Right XSHUT | 26 | — |
| ToF Front XSHUT | 13 | Moved off strapping pin GPIO12 |
| ToF Left XSHUT | 25 | — |
| UART TX (Pi→ESP32) | 14 (Pi side) | Reserved, not yet implemented |
| UART RX (ESP32→Pi) | 15 (Pi side) | Reserved, not yet implemented |

All 15 GPIOs above are unique — no pin conflicts in the current pinout.

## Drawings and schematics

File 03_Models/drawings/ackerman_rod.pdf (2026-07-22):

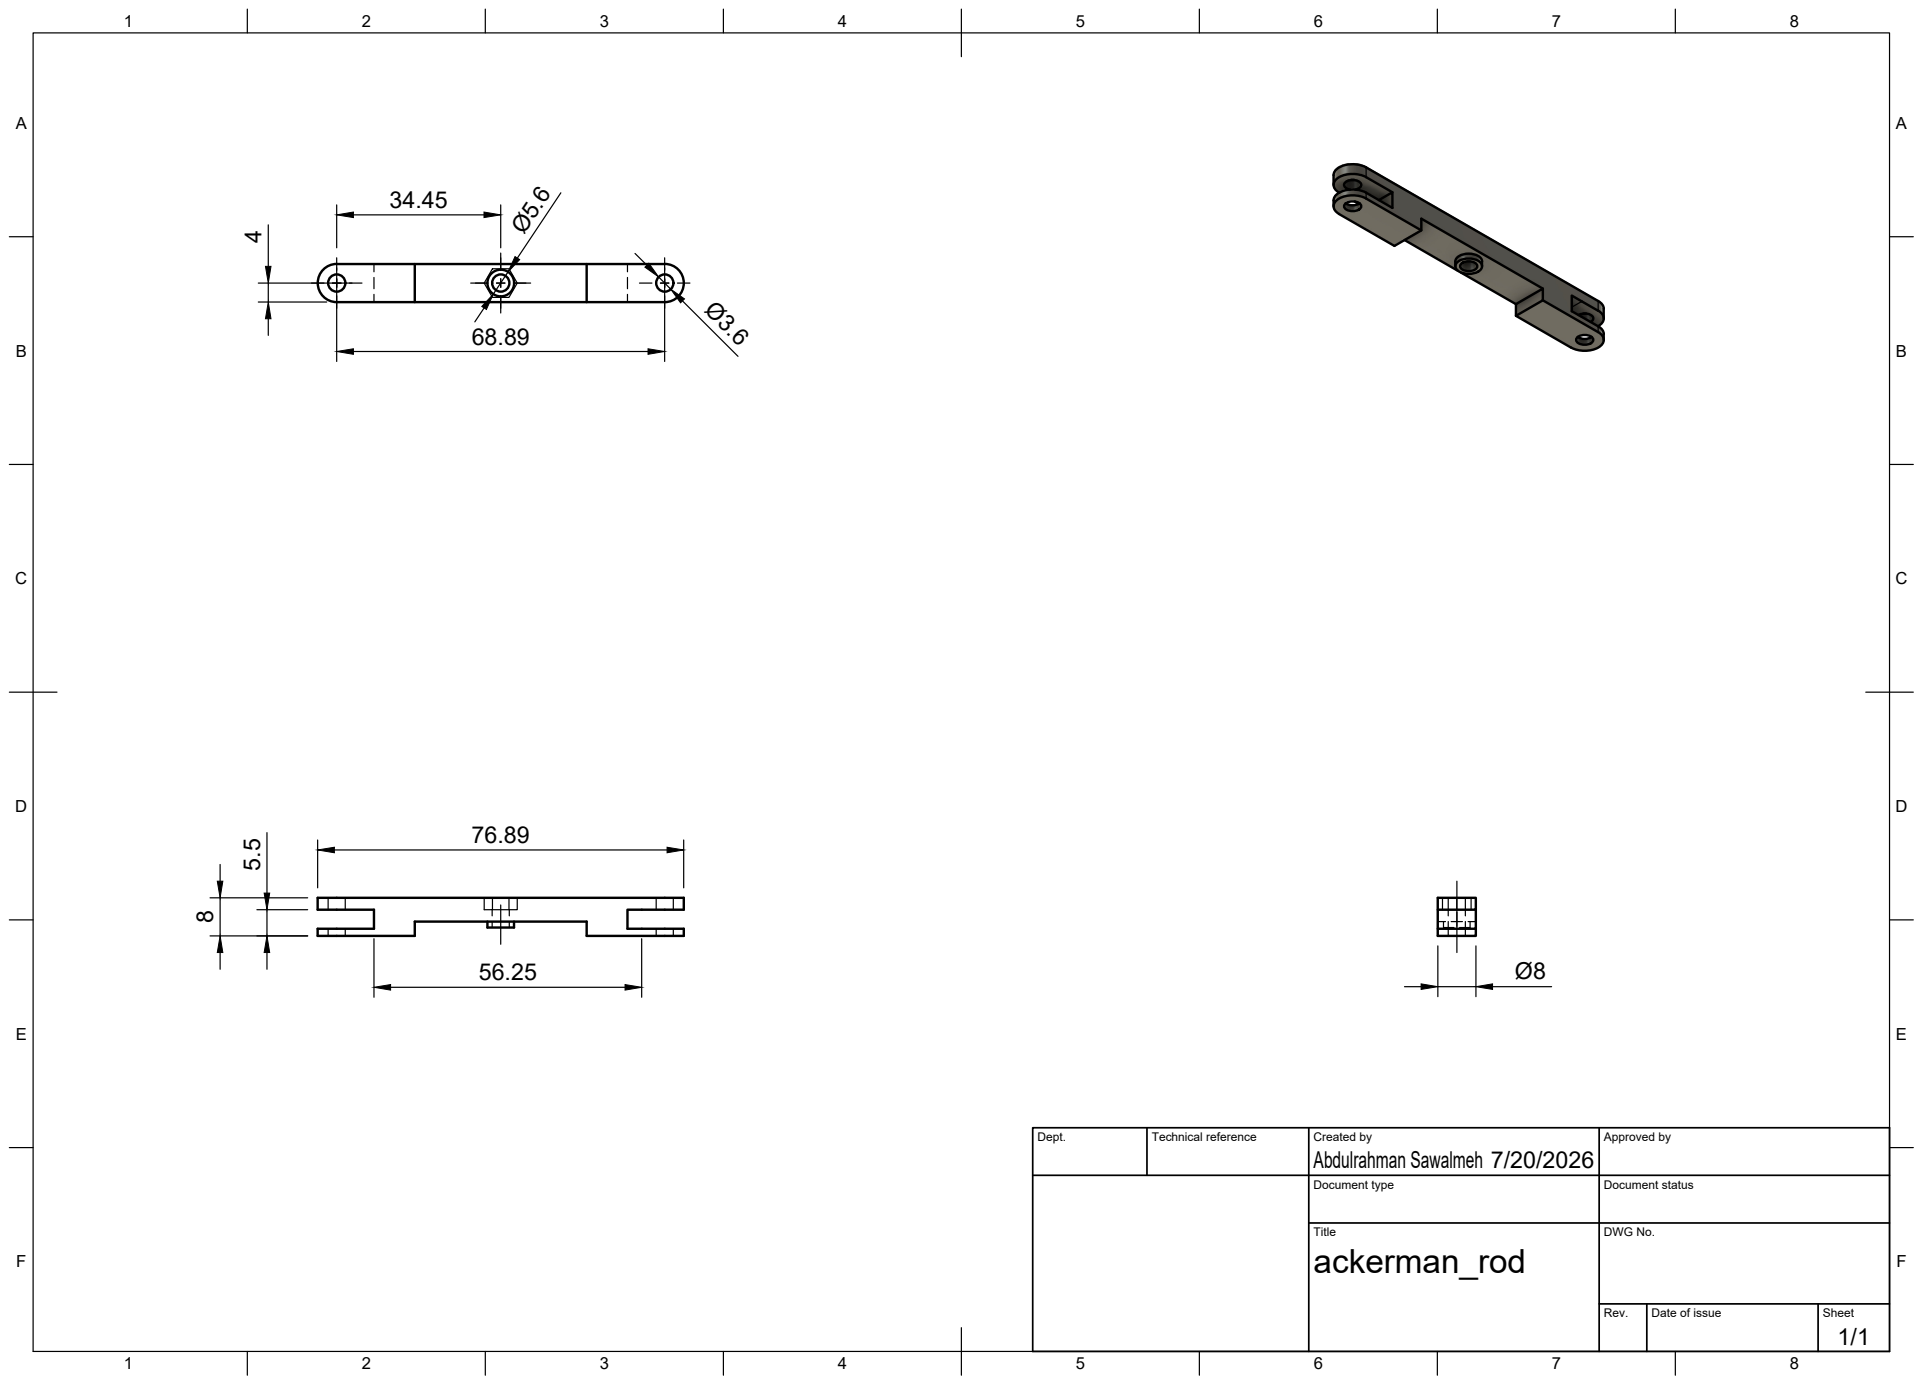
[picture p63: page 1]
Title; DWG No.; Rev.; Date of issue; Sheet

Dept. | Technical reference | Created by Abdulrahman Sawalmeh 7/20/2026 | Approved by

Document type | Document status

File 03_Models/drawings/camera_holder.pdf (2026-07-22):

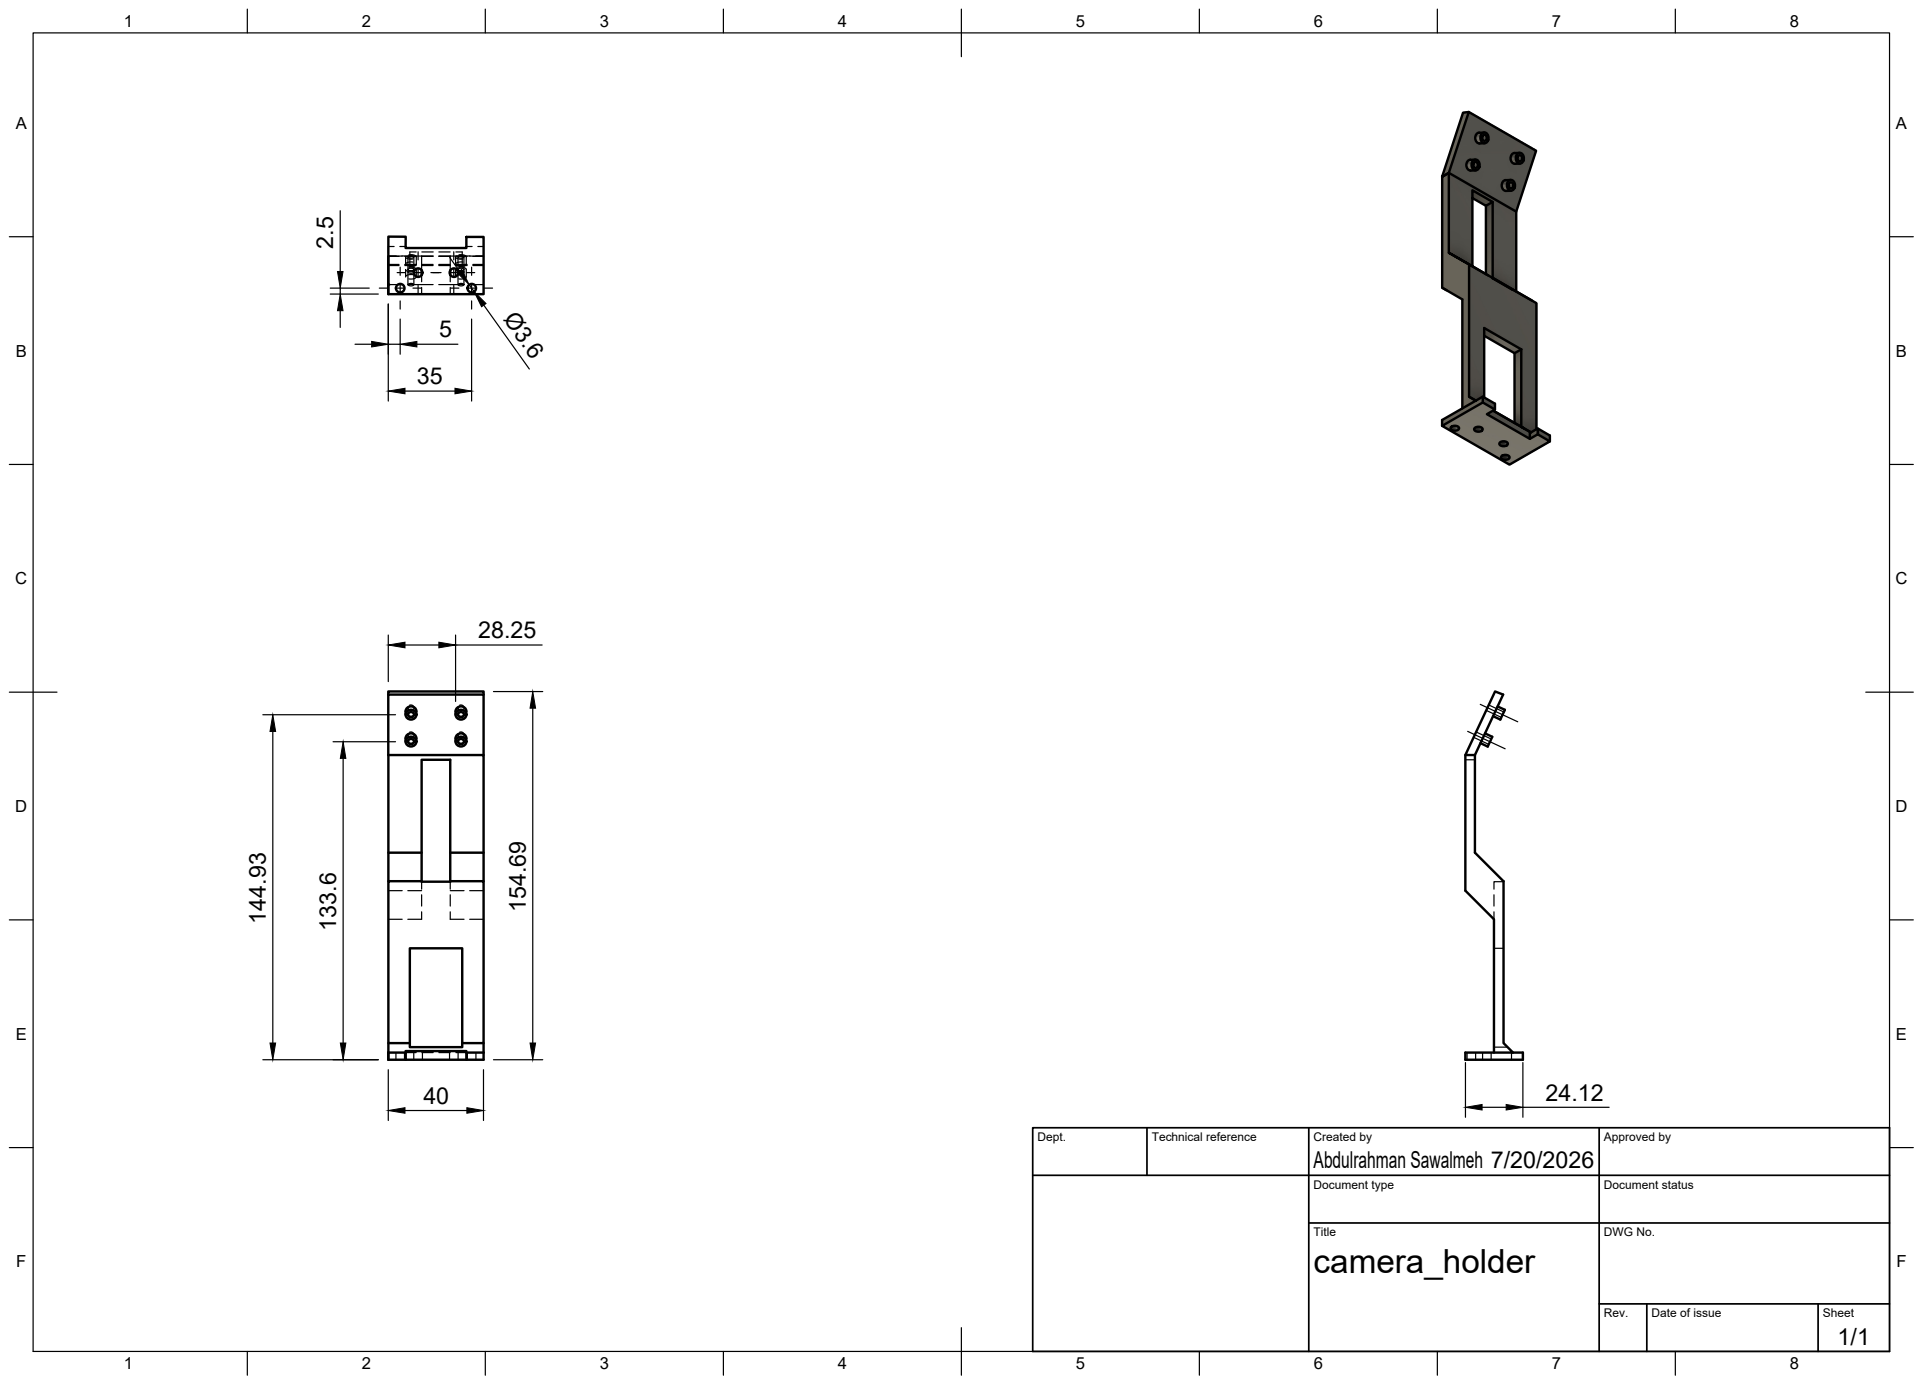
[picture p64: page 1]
Title; DWG No.; Rev.; Date of issue; Sheet; Abdulrahman Sawalmeh 154.69

Dept. | Technical reference | Created by 7/20/2026 | Approved by

Document type | Document status

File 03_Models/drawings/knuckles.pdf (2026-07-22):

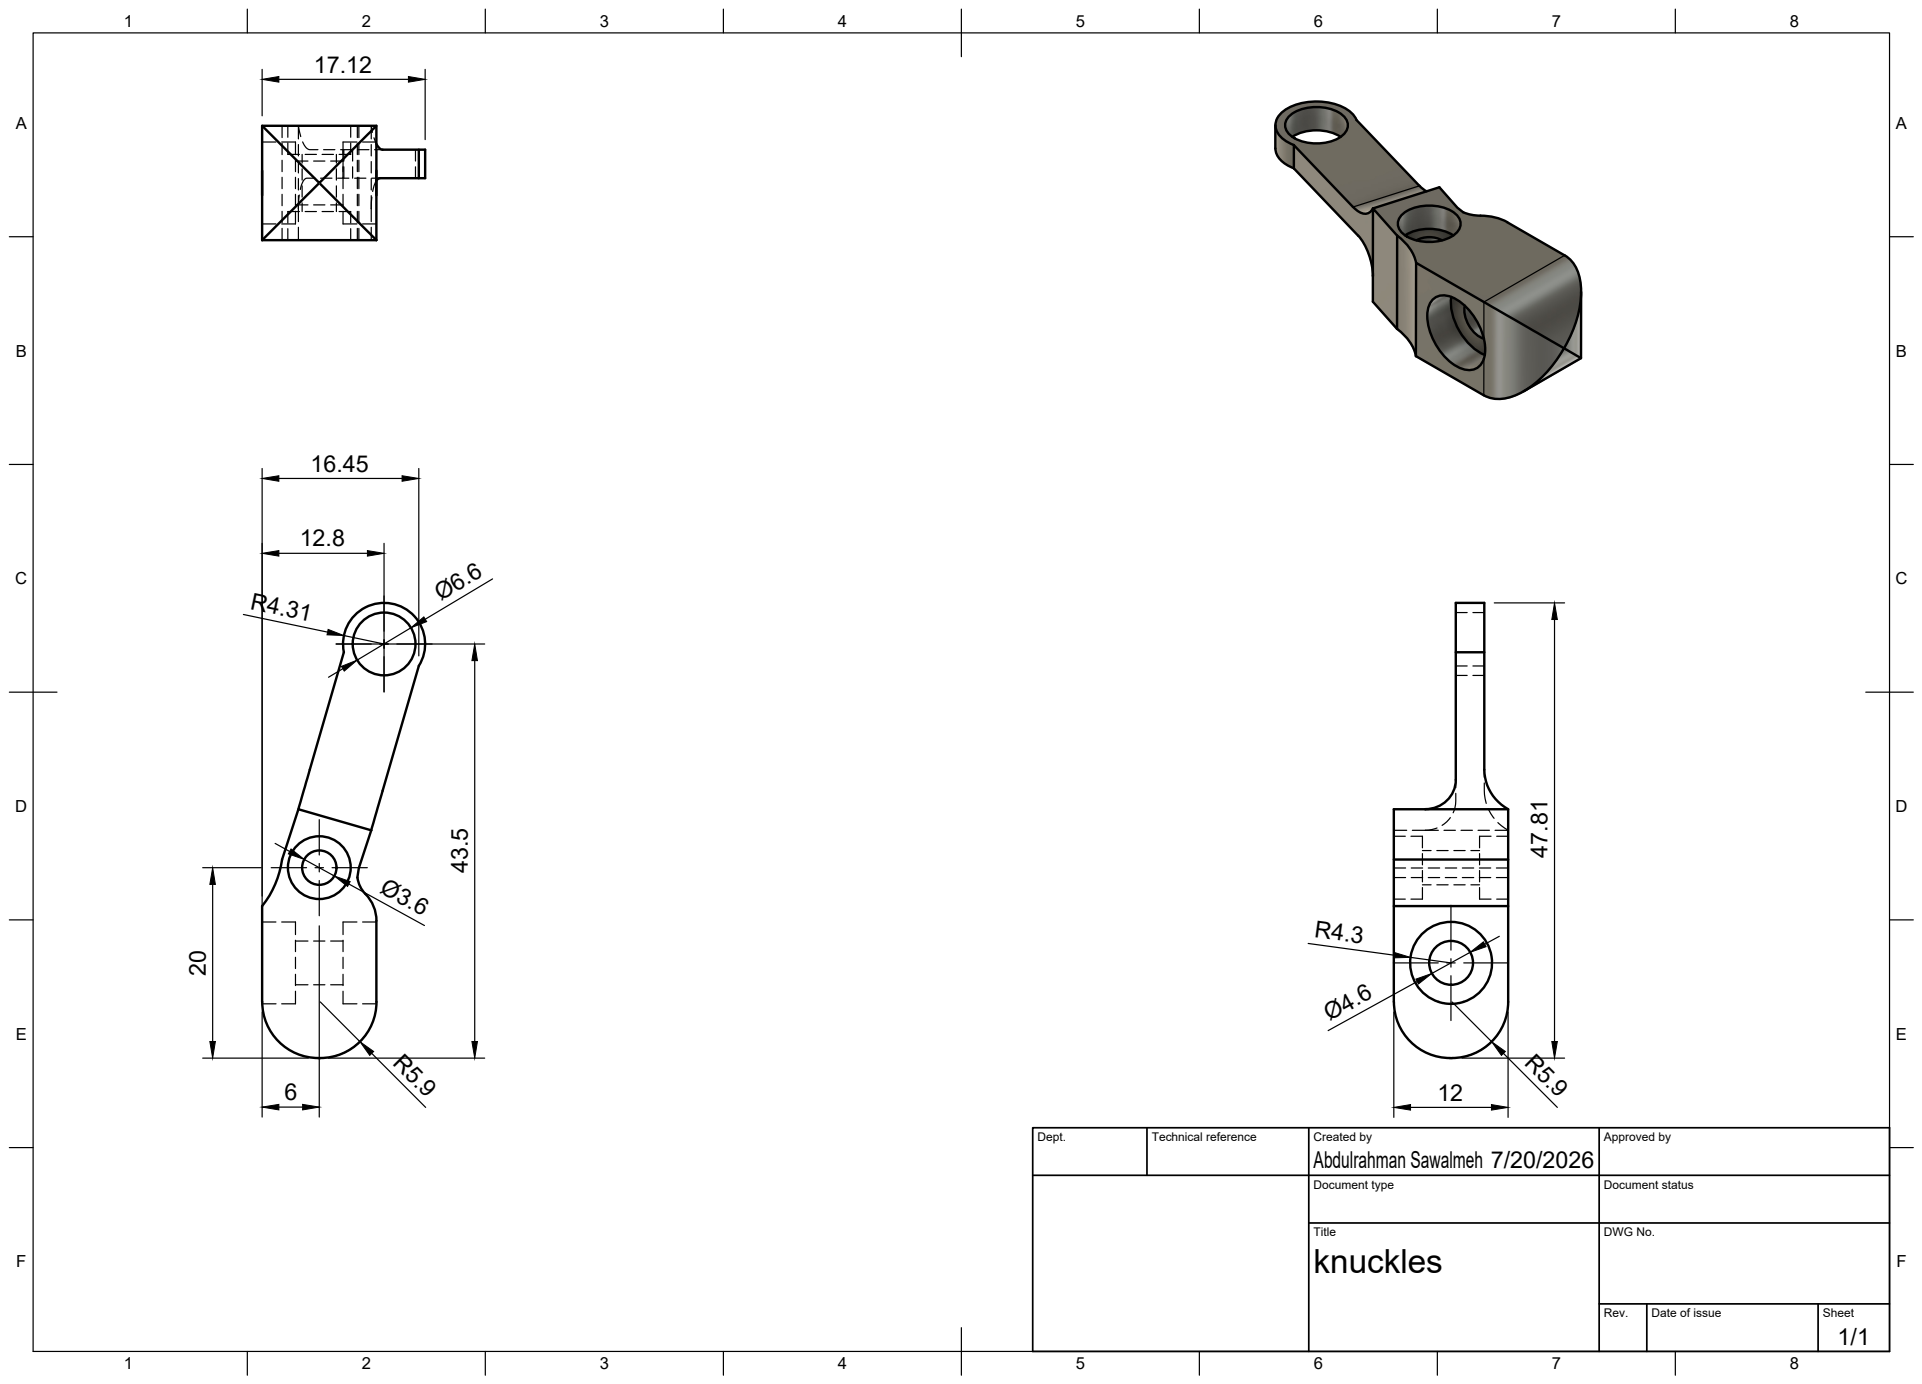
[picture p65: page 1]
Title; DWG No.; Rev.; Date of issue; Sheet; Abdulrahman Sawalmeh 43.5

Dept. | Technical reference | Created by 7/20/2026 | Approved by

Document type | Document status

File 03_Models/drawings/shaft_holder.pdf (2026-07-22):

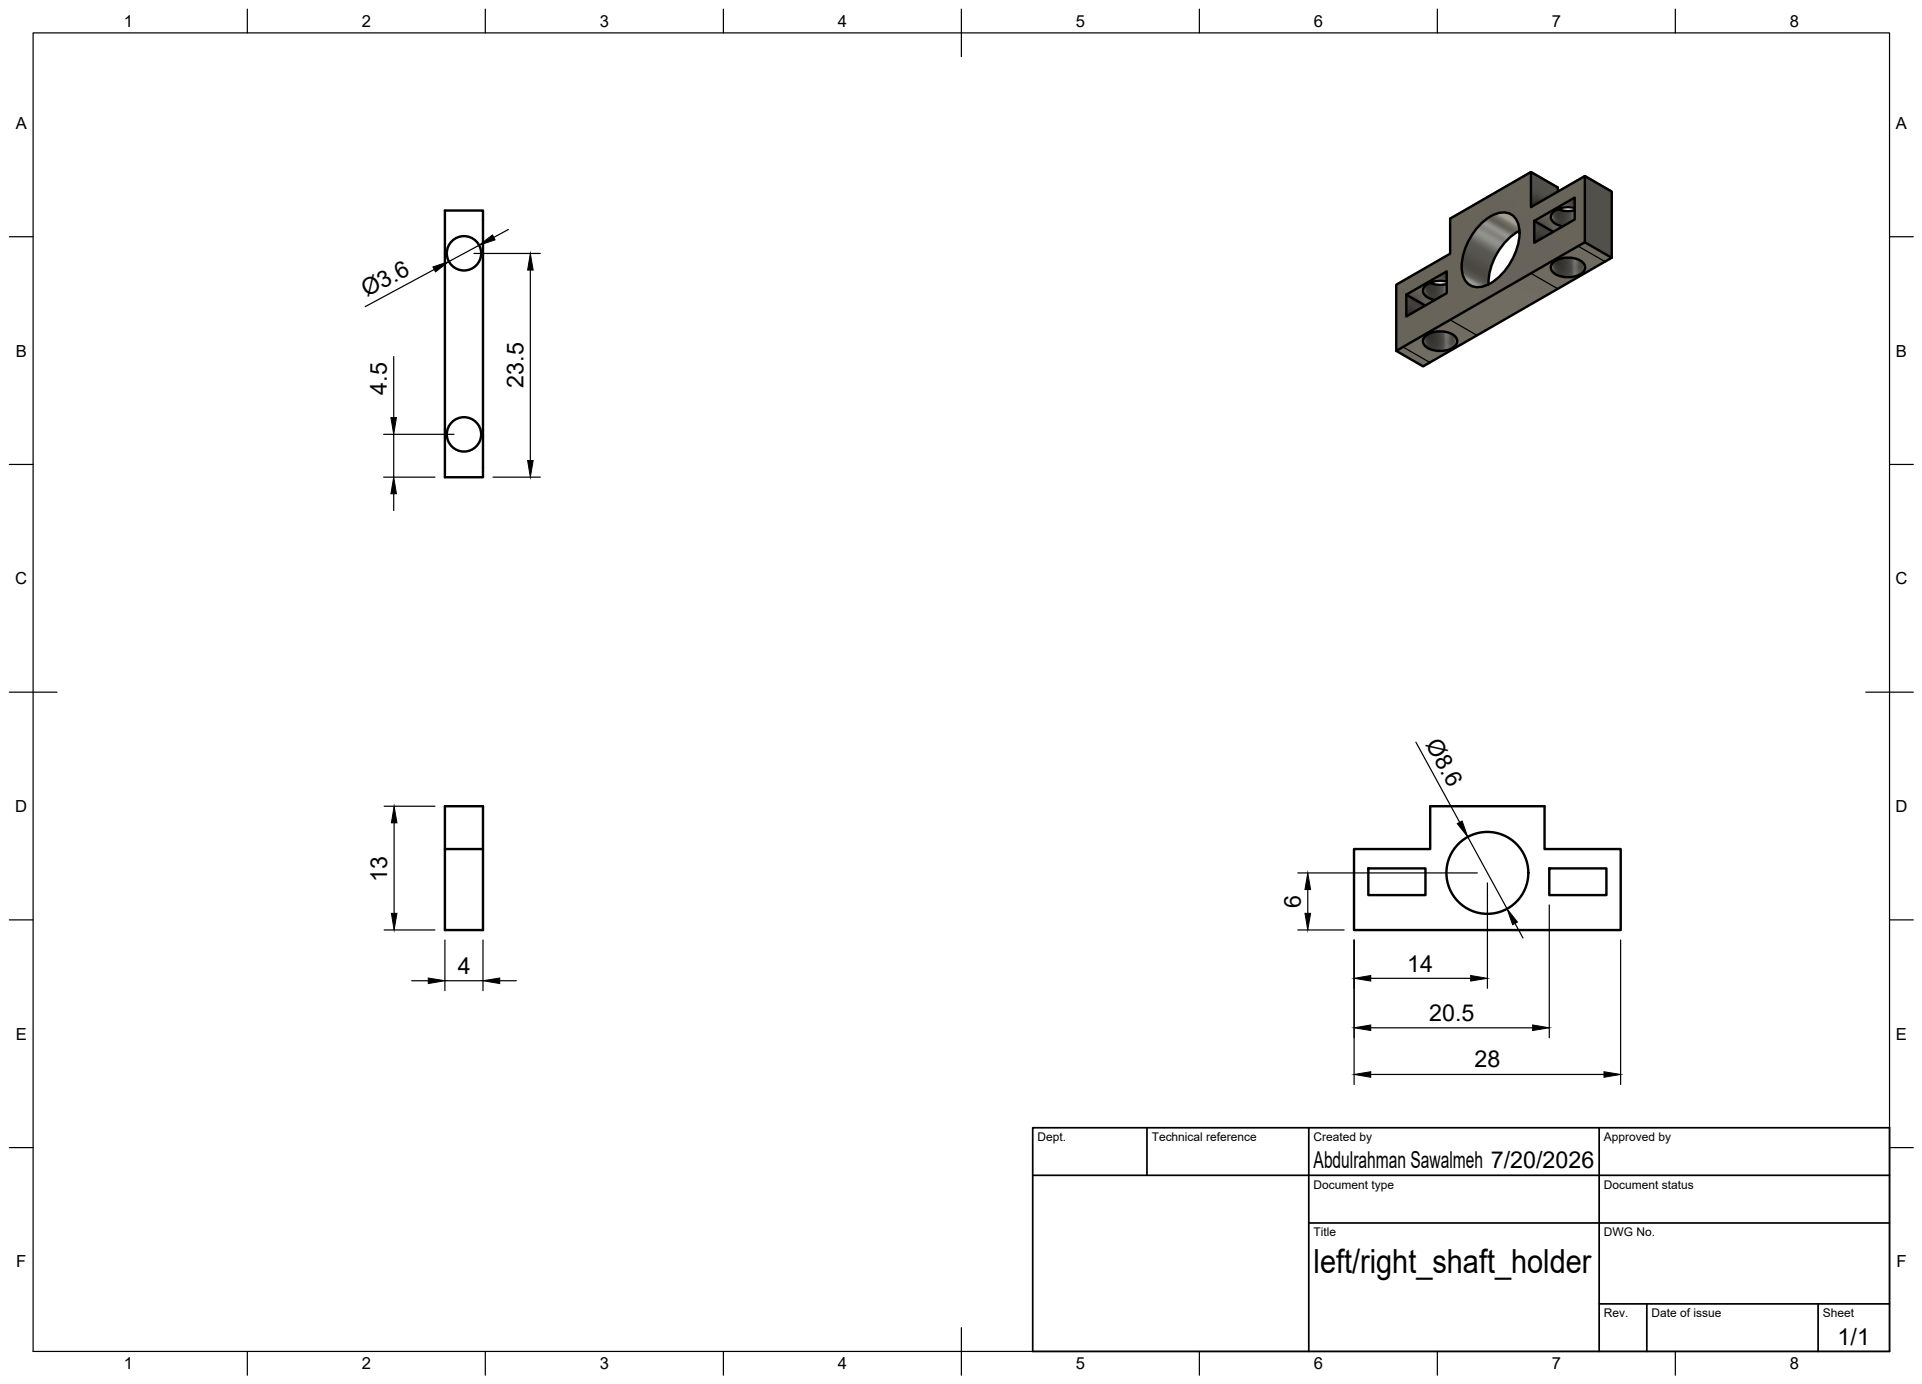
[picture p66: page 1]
Title; DWG No.; Rev.; Date of issue; Sheet; Abdulrahman Sawalmeh 13

Dept. | Technical reference | Created by 7/20/2026 | Approved by

Document type | Document status

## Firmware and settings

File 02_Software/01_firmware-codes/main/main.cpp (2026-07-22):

#include "ToF.h"

#include "RPI.h"
#include "esp_log.h"
#include "forward_control.h"
#include "freertos/FreeRTOS.h"
#include "freertos/semphr.h"
#include "freertos/task.h"
#include "imu_bno055.h"
#include "motor_control.h"
#include "pid_tuner.h"
#include "task_RPI.h"
#include "task_algorithm.h"
#include "task_control.h"
#include "turn_control.h"
#include "wifi_telemetry.h"
#include <i2c_bus.h>
#include <task_imu.h>
#include <task_tof.h>
extern "C" {
#include "encoder.h"
#include "servo_control.h"
}

static bno055_imu_t imu;
static turn_ctrl_t g_turn;
static forward_ctrl_t g_fwd;

SemaphoreHandle_t yaw_mutex = nullptr;
SemaphoreHandle_t tof_mutex = nullptr;
SemaphoreHandle_t rpi_mutex = nullptr;

static void init_motor(void) {
  tb6612_setup();
  motor_enable();
  stop();
}

static void init_servo(void) {
  servo_init();
  // servo_center();
}

static void init_encoder(void) {
  encoder_setup();
  encoder_reset();
}

static void init_imu(void) {
  esp_err_t err = bno_setup(&imu, IMU_PORT, IMU_ADDR);
  if (err != ESP_OK) {
    ESP_LOGE("MAIN", "BNO055 init failed: %s", esp_err_to_name(err));
    while (true)
      vTaskDelay(pdMS_TO_TICKS(1000));
  }
  ESP_LOGI("MAIN", "BNO055 ready.");
}

static ToF tof(TOF_PORT, TOF_ADDR);
static void init_tof(void) { tof.tof_setup(); }

static void init_controllers(void) {
  turn_init(&g_turn);
  forward_init(&g_fwd);
}

static void init_rpi_uart(void) {
  esp_err_t err = rpi_uart_setup();
  if (err != ESP_OK) {
    ESP_LOGE("MAIN", "RPI UART init failed: %s", esp_err_to_name(err));
    while (true)
      vTaskDelay(pdMS_TO_TICKS(1000));
  }
}
static void init_mutexes(void) {
  yaw_mutex = xSemaphoreCreateMutex();
  tof_mutex = xSemaphoreCreateMutex();
  rpi_mutex = xSemaphoreCreateMutex();
  if (!yaw_mutex || !tof_mutex || !rpi_mutex) {
    ESP_LOGE("MAIN", "Mutex creation failed");
    while (true)
      vTaskDelay(pdMS_TO_TICKS(1000));
  }
}

static float wrap180(float deg) {
  while (deg > 180.0f)
    deg -= 360.0f;
  while (deg < -180.0f)
    deg += 360.0f;
  return deg;
}

extern "C" void app_main(void) {

  wifi_telemetry_init();

  // ====== I2C =======
  esp_err_t err = i2c_setup();
  if (err != ESP_OK) {
    ESP_LOGE("MAIN", "I2C init failed: %s", esp_err_to_name(err));
    while (true)
      vTaskDelay(pdMS_TO_TICKS(1000));
  }

  // ====== Driving Logic ======
  init_motor();
  // ==============================

  // ====== Servo ======
  init_servo();
  // ==============================

  // ====== Encoder ======
  init_encoder();
  // ==============================

  // ====== IMU ======
  init_imu();
  // ==============================

  // ====== ToF ======
  // init_tof();
  // ==============================

  // ====== rpi uart ======
  // init_rpi_uart();
  // ==============================

  // ====== Mutexes ======
  init_mutexes();
  // ==============================

  // ====== Control Logic ======
  init_controllers();
  // ==============================
  // ====== Start Tasks =========
  // tof_task_start(&tof, tof_mutex);
  imu_task_start(&imu, yaw_mutex);
  // rpi_task_start(rpi_mutex);
  vTaskDelay(pdMS_TO_TICKS(50));
  yaw_zero();
  vTaskDelay(pdMS_TO_TICKS(100));

  control_task_start(&g_turn, &g_fwd, yaw_mutex, tof_mutex);
  pid_tuner_start(&g_fwd, &g_turn);
  // algorithm_task_start();
  // move_forward(100);
  // ============================
  int i = 0;
  bool flag = false;

  char buf[256];
  servo_center();

  float heading = 0.0f;
  bool tflag = true;

  while (true) {
    if (!pid_tuner_running()) {
      vTaskDelay(pdMS_TO_TICKS(100));
      continue;
    }

    move_forward(90);
    ctrl_request_forward(heading);
    if (tflag) {
      vTaskDelay(pdMS_TO_TICKS(2300));
      tflag = false;
    }

    else {
      vTaskDelay(pdMS_TO_TICKS(1300));
    }

    heading = wrap180(heading - 90.0f);
    ctrl_request_turn(heading);
    while (!ctrl_turn_done()) {
      vTaskDelay(pdMS_TO_TICKS(10));
    }

    vTaskDelay(pdMS_TO_TICKS(500));
  }
}

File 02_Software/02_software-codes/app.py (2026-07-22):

"""
telemetry_gui.py — WRO robot telemetry dashboard (PyQt5 GUI version)

Listens for JSON UDP packets from the ESP32 and displays them in a
graphical dashboard. Click any sensor card to open its detail panel
with a live graph and a scrollable history table.

CHANGES from the ToF-era version:
- Side ToF (L/R) removed entirely — replaced by camera-derived NAV
  wall-following data and OBST pillar data (both relayed by the ESP32
  from the Pi over UART).
- History capture now runs continuously in the background for ALL
  sensor groups regardless of which card is focused. Switching cards
  no longer clears anything — it just changes what's displayed.
- Each detail panel has an explicit "Restart history" button that
  clears ONLY that sensor's stored history, on demand.

Expected packet shape (all fields optional):
{
  "tof":   {"F": 340},
  "imu":   {"yaw": 45.2},
  "enc":   {"mm": 230},
  "nav":   {"L": 72, "R": 18},
  "obst":  {"color": "GREEN", "dist": 280, "lat": 60},
  "state": "FORWARD",
  "turn":  2,
  "lap":   1
}

Install once:
    pip install PyQt5 pyqtgraph

Run:
    python3 telemetry_gui.py
"""

import csv
import json
import socket
import threading
import time
from collections import deque

from PyQt5.QtCore import Qt, QTimer, pyqtSignal, QObject
from PyQt5.QtGui import QFont
from PyQt5.QtWidgets import (
    QApplication,
    QWidget,
    QMainWindow,
    QVBoxLayout,
    QHBoxLayout,
    QLabel,
    QFrame,
    QPushButton,
    QSlider,
    QTableWidget,
    QTableWidgetItem,
    QFileDialog,
    QSplitter,
)
import pyqtgraph as pg

# ---------------------------------------------------------------------------
# Config
# ---------------------------------------------------------------------------
LISTEN_PORT = 5005
STALE_TIMEOUT_S = 3.0
HISTORY_SECONDS = 60  # how much time-series history the live graph shows
MAX_TABLE_ROWS = 2000
MAX_HISTORY_POINTS = 5000  # per-series cap on stored (t, value) points
# ---------------------------------------------------------------------------

SENSOR_GROUPS = {
    "nav": {"title": "Wall Following (Camera)", "columns": ["L", "R"]},
    "obst": {"title": "Obstacle Pillar (Camera)", "columns": ["dist", "lat"]},
    "imu": {"title": "IMU Yaw", "columns": ["yaw"]},
    "state": {"title": "Algorithm / Odometry", "columns": ["enc_mm", "front_mm"]},
}


# ---------------------------------------------------------------------------
# UDP receiver — background thread, emits Qt signals
# ---------------------------------------------------------------------------
class UdpReceiver(QObject):
    packet_received = pyqtSignal(dict)

    def __init__(self, port):
        super().__init__()
        self.port = port
        self._running = True

    def start(self):
        threading.Thread(target=self._run, daemon=True).start()

    def stop(self):
        self._running = False

    def _run(self):
        sock = socket.socket(socket.AF_INET, socket.SOCK_DGRAM)
        sock.setsockopt(socket.SOL_SOCKET, socket.SO_REUSEADDR, 1)
        sock.bind(("0.0.0.0", self.port))
        sock.settimeout(0.5)

        while self._running:
            try:
                data, _ = sock.recvfrom(2048)
            except socket.timeout:
                continue
            except OSError:
                break

            text = data.decode("utf-8", errors="replace").strip()
            try:
                parsed = json.loads(text)
            except json.JSONDecodeError:
                parsed = {"raw": text}

            self.packet_received.emit(parsed)


# ---------------------------------------------------------------------------
# Color helpers
# ---------------------------------------------------------------------------
def color_for_nav(pct):
    """High wall presence = green (safe/expected), low = red (opening/corner)."""
    if pct is None:
        return "#666666"
    if pct < 25:
        return "#e74c3c"
    if pct < 50:
        return "#f1c40f"
    return "#2ecc71"


def color_for_obst(color_name):
    if color_name == "RED":
        return "#e74c3c"
    if color_name == "GREEN":
        return "#2ecc71"
    return "#666666"


# ---------------------------------------------------------------------------
# Sensor card — clickable summary box
# ---------------------------------------------------------------------------
class SensorCard(QFrame):
    clicked = pyqtSignal(str)

    def __init__(self, key, title):
        super().__init__()
        self.key = key
        self.setFrameShape(QFrame.StyledPanel)
        self.setStyleSheet(
            "QFrame { background-color: #1e1e2e; border-radius: 10px; "
            "border: 2px solid #313244; }"
            "QFrame:hover { border: 2px solid #89b4fa; }"
        )
        self.setCursor(Qt.PointingHandCursor)
        self.setMinimumHeight(160)

        layout = QVBoxLayout(self)
        title_label = QLabel(title)
        title_label.setStyleSheet("color: #cdd6f4; font-weight: bold; border: none;")
        title_label.setFont(QFont("Sans", 12))
        layout.addWidget(title_label)

        self.body = QLabel("--")
        self.body.setStyleSheet("color: #a6e3a1; border: none;")
        self.body.setFont(QFont("Monospace", 11))
        self.body.setWordWrap(True)
        layout.addWidget(self.body)
        layout.addStretch()

    def mousePressEvent(self, event):
        self.clicked.emit(self.key)

    def set_body_html(self, html):
        self.body.setText(html)
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

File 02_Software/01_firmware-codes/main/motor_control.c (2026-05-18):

#include "motor_control.h"

#include <stdbool.h>
#include <stdint.h>

#include "driver/gpio.h"
#include "driver/ledc.h"
#include "esp_err.h"
#include "freertos/FreeRTOS.h"
#include "freertos/task.h"

// =====================================================================================
// TB6612FNG mapping (single motor)
// IN1 = GPIO_NUM_25
// IN2 = GPIO_NUM_26
// PWM = GPIO_NUM_16
// STBY = GPIO_NUM_27
// =====================================================================================

#define MOTOR_IN1_GPIO GPIO_NUM_18
#define MOTOR_IN2_GPIO GPIO_NUM_5
#define MOTOR_PWM_GPIO GPIO_NUM_17
#define MOTOR_STBY_GPIO GPIO_NUM_19

// =====================================================================================
// LEDC config
// =====================================================================================
#define MOTOR_TIMER LEDC_TIMER_0
#define MOTOR_CHANNEL LEDC_CHANNEL_0
#define MOTOR_MODE LEDC_LOW_SPEED_MODE
#define MOTOR_RES LEDC_TIMER_10_BIT
#define MOTOR_FREQ_HZ 20000
#define MOTOR_MAX_DUTY ((1 << 10) - 1) // 1023 for 10-bit

// =====================================================================================
// Helpers
// =====================================================================================
static inline uint32_t pct_to_duty(uint8_t pct) {
  if (pct > 100)
    pct = 100;
  return ((uint32_t)MOTOR_MAX_DUTY * pct) / 100;
}

static inline void pwm_set(uint32_t duty) {
  ledc_set_duty(MOTOR_MODE, MOTOR_CHANNEL, duty);
  ledc_update_duty(MOTOR_MODE, MOTOR_CHANNEL);
}

// =====================================================================================
// Low-level direction control
// =====================================================================================
static inline void motor_forward(uint32_t duty) {
  gpio_set_level(MOTOR_IN1_GPIO, 1);
  gpio_set_level(MOTOR_IN2_GPIO, 0);
  pwm_set(duty);
}

static inline void motor_reverse(uint32_t duty) {
  gpio_set_level(MOTOR_IN1_GPIO, 0);
  gpio_set_level(MOTOR_IN2_GPIO, 1);
  pwm_set(duty);
}

static inline void motor_brake(void) {
  gpio_set_level(MOTOR_IN1_GPIO, 1);
  gpio_set_level(MOTOR_IN2_GPIO, 1);
  pwm_set(0);
}

static inline void motor_coast(void) {
  gpio_set_level(MOTOR_IN1_GPIO, 0);
  gpio_set_level(MOTOR_IN2_GPIO, 0);
  pwm_set(0);
}

// =====================================================================================
// Init
// =====================================================================================
void tb6612_setup(void) {
  // GPIO init
  gpio_config_t io_conf = {
      .pin_bit_mask = (1ULL << MOTOR_STBY_GPIO) | (1ULL << MOTOR_IN1_GPIO) |
                      (1ULL << MOTOR_IN2_GPIO),
      .mode = GPIO_MODE_OUTPUT,
      .pull_up_en = GPIO_PULLUP_DISABLE,
      .pull_down_en = GPIO_PULLDOWN_DISABLE,
      .intr_type = GPIO_INTR_DISABLE,
  };
  ESP_ERROR_CHECK(gpio_config(&io_conf));

  // Start in standby, coast
  gpio_set_level(MOTOR_STBY_GPIO, 0);
  gpio_set_level(MOTOR_IN1_GPIO, 0);
  gpio_set_level(MOTOR_IN2_GPIO, 0);

  // LEDC timer
  ledc_timer_config_t timer = {
      .speed_mode = MOTOR_MODE,
      .timer_num = MOTOR_TIMER,
      .duty_resolution = MOTOR_RES,
      .freq_hz = MOTOR_FREQ_HZ,
      .clk_cfg = LEDC_AUTO_CLK,
  };
  ESP_ERROR_CHECK(ledc_timer_config(&timer));

  // LEDC channel
  ledc_channel_config_t ch = {
      .speed_mode = MOTOR_MODE,
      .channel = MOTOR_CHANNEL,
      .timer_sel = MOTOR_TIMER,
      .intr_type = LEDC_INTR_DISABLE,
      .gpio_num = MOTOR_PWM_GPIO,
      .duty = 0,
      .hpoint = 0,
  };
  ESP_ERROR_CHECK(ledc_channel_config(&ch));
}

void motor_enable(void) { gpio_set_level(MOTOR_STBY_GPIO, 1); }
void motor_disable(void) { gpio_set_level(MOTOR_STBY_GPIO, 0); }

// =====================================================================================
// Public API
// =====================================================================================
void move_forward(uint8_t speed) { motor_forward(pct_to_duty(speed)); }
void move_reverse(uint8_t speed) { motor_reverse(pct_to_duty(speed)); }
void stop(void) { motor_brake(); }
void coast(void) { motor_coast(); }

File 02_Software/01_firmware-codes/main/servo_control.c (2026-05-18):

#include "servo_control.h"
#include "driver/gpio.h"
#include "driver/ledc.h"

// ── Pin
// ───────────────────────────────────────────────────────────────────────
#define SERVO_PIN GPIO_NUM_32

// ── LEDC
// ──────────────────────────────────────────────────────────────────────
#define SERVO_TIMER LEDC_TIMER_1     // TIMER_0 is reserved for motor
#define SERVO_CHANNEL LEDC_CHANNEL_1 // CHANNEL_0 is reserved for motor
#define SERVO_MODE LEDC_LOW_SPEED_MODE
#define SERVO_FREQ_HZ 50
#define SERVO_RESOLUTION LEDC_TIMER_16_BIT // 0–65535
#define SERVO_MAX_DUTY ((1 << 16) - 1)     // 65535

// ── Pulse width bounds (microseconds) ────────────────────────────────────────
// Verify these against your specific servo datasheet
#define SERVO_MIN_US 500      // full left  (-90°)
#define SERVO_MID_US 1500     // center     (  0°)
#define SERVO_MAX_US 2500     // full right (+90°)
#define SERVO_PERIOD_US 20000 // 1 / 50Hz = 20ms

// ── Helper
// ────────────────────────────────────────────────────────────────────
static inline uint32_t us_to_duty(uint16_t pulse_us) {
  return ((uint32_t)pulse_us * SERVO_MAX_DUTY) / SERVO_PERIOD_US;
}

// ── Public API
// ────────────────────────────────────────────────────────────────
void servo_init(void) {
  ledc_timer_config_t timer = {
      .speed_mode = SERVO_MODE,
      .timer_num = SERVO_TIMER,
      .duty_resolution = SERVO_RESOLUTION,
      .freq_hz = SERVO_FREQ_HZ,
      .clk_cfg = LEDC_AUTO_CLK,
  };
  ESP_ERROR_CHECK(ledc_timer_config(&timer));

  ledc_channel_config_t ch = {
      .speed_mode = SERVO_MODE,
      .channel = SERVO_CHANNEL,
      .timer_sel = SERVO_TIMER,
      .intr_type = LEDC_INTR_DISABLE,
      .gpio_num = SERVO_PIN,
      .duty = us_to_duty(SERVO_MID_US), // center on boot
      .hpoint = 0,
  };
  ESP_ERROR_CHECK(ledc_channel_config(&ch));
}

void set_angle(int angle_deg) {
  if (angle_deg > 90)
    angle_deg = 90;
  if (angle_deg < -90)
    angle_deg = -90;

  uint16_t pulse_us;
  if (angle_deg >= 0)
    pulse_us =
        SERVO_MID_US + (int32_t)angle_deg * (SERVO_MAX_US - SERVO_MID_US) / 90;
  else
    pulse_us =
        SERVO_MID_US + (int32_t)angle_deg * (SERVO_MID_US - SERVO_MIN_US) / 90;

  ledc_set_duty(SERVO_MODE, SERVO_CHANNEL, us_to_duty(pulse_us));
  ledc_update_duty(SERVO_MODE, SERVO_CHANNEL);
}

void servo_center(void) { set_angle(0); }

void servo_disable(void) { ledc_stop(SERVO_MODE, SERVO_CHANNEL, 0); }

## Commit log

2026-03-08 WRO 2025 researches
    [Car_Schematic.fzz]
2026-03-08 Organize the search, remove unnecessary things
    [Car_Schematic.fzz]
2026-03-17 Add a reference of how to choose a motor
2026-03-18 Update motor selection document structure
    Removed motor evaluation section and updated list.
2026-03-24 Remove differential consideration section from motor guide
    Removed section on the differential and its considerations.
2026-04-23 Schematic Added
2026-04-23 Schematic Modification, add titles
2026-04-23 add 6v rail for servo
2026-05-04 Make the initial sensors library
2026-07-15 Add A document about th steering
2026-07-15 Fix links on 01-BOM
2026-07-17 Add powersystem to README.md
2026-07-19 Update print statement from 'Hello' to 'Goodbye'
2026-07-19 Add new Images to support Software/PID
2026-07-19 Add PID explinations
2026-07-22 Add print-ready STL files for all 14 parts for the Palestine national competition
    [ackerman_rod.stl, back_top.stl, camera_holder.stl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]
2026-07-22 Add dimensioned technical drawings for all printed parts
2026-07-22 Add missing servo arm and differential cup STLs
    [differantial_cup.stl, servo_arm.stl]
2026-07-23 Restructure media folders: t_photos, v-photos, videos, rename Attachments, update README refrences
